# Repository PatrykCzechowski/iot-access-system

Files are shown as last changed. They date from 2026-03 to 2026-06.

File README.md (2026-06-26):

# AccessControl

An IoT access control system: contactless NFC cards are read by ESP32-based
readers, access rights are verified centrally by a .NET backend, and electric
locks are released over MQTT. The whole system is managed from a Blazor
WebAssembly admin panel.

**Stack:** .NET 10 (Clean Architecture + CQRS) · Blazor WebAssembly + MudBlazor 9 ·
PostgreSQL (EF Core) · MQTT (Mosquitto) · SignalR · mDNS · ESP32-S3 firmware
(PlatformIO) · Docker Compose.

## Features

- Contactless NFC card authorization with server-side permission checks.
- Access model: **Card → Cardholder → Access Profile → Zones**.
- Device management: mDNS auto-discovery, remote MQTT provisioning, per-device
  configuration, live online/offline status.
- Card enrollment straight from a reader (enrollment mode).
- Full audit trail of every access attempt (granted **and** denied), streamed
  live to the UI via SignalR.
- JWT authentication with the `Admin` role, forced password change on first
  login, and rate-limited auth endpoints.

## Web UI

The administration panel is a Blazor WebAssembly app (MudBlazor, Material
Design 3). Screenshots below are captured from a running instance with seeded
demo data and live access logs.

<table>
<tr>
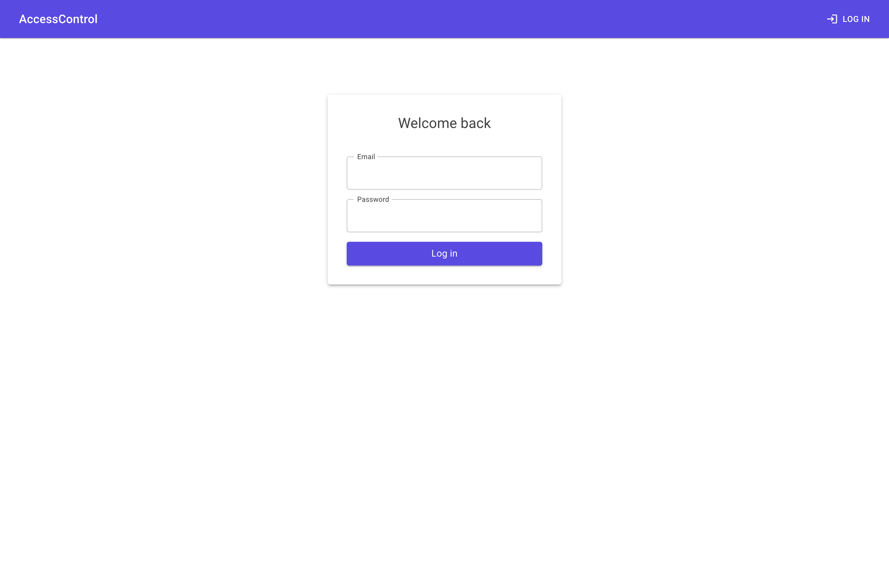
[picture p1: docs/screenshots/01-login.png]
Login screen
<td width="50%"><br><sub><b>Login</b> — JWT authentication</sub></td>
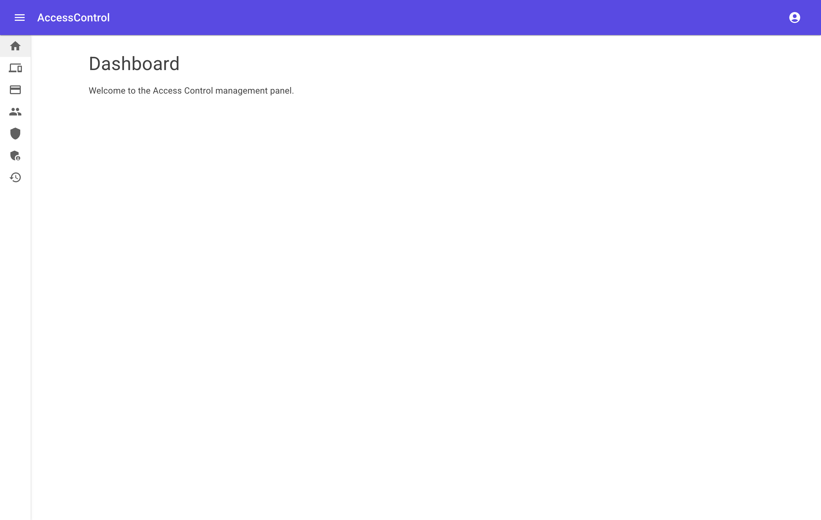
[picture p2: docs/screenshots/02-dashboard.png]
Dashboard
<td width="50%"><br><sub><b>Dashboard</b> — management home</sub></td>
</tr>
<tr>
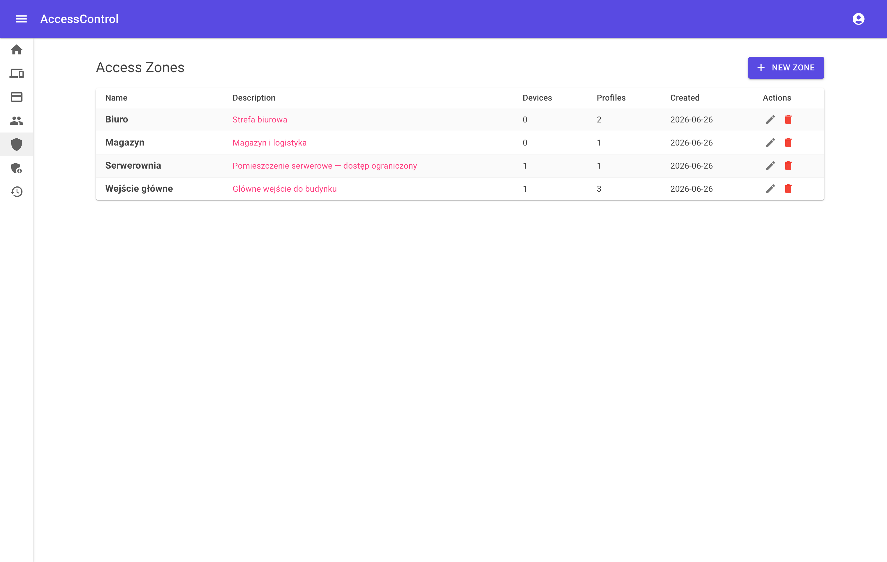
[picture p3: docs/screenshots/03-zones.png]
Zones
<td width="50%"><br><sub><b>Zones</b> — physical access areas</sub></td>
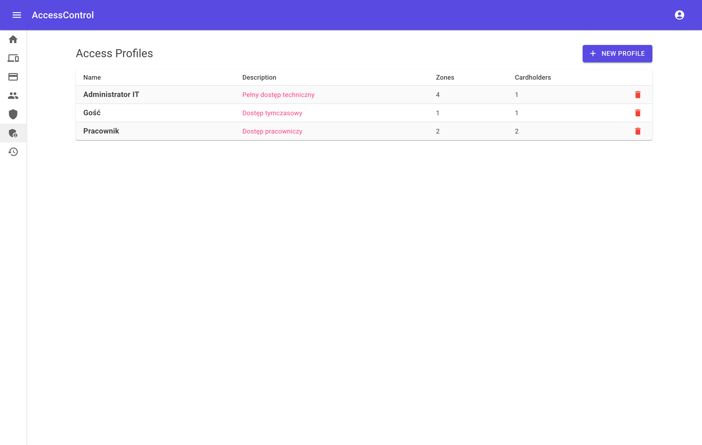
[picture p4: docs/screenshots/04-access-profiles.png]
Access profiles
<td width="50%"><br><sub><b>Access Profiles</b> — permission sets over zones</sub></td>
</tr>
<tr>
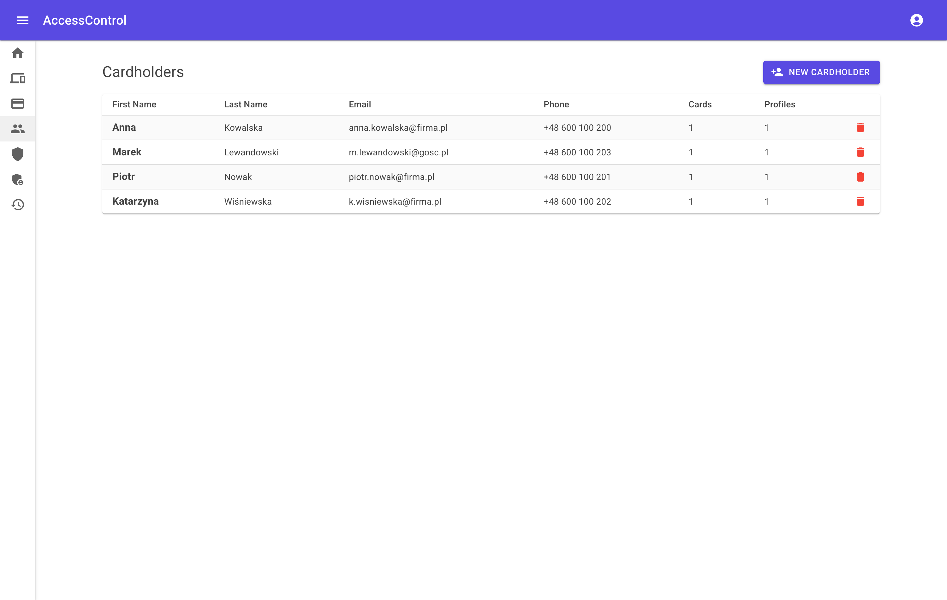
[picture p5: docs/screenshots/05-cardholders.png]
Cardholders
<td width="50%"><br><sub><b>Cardholders</b> — people and their profiles</sub></td>
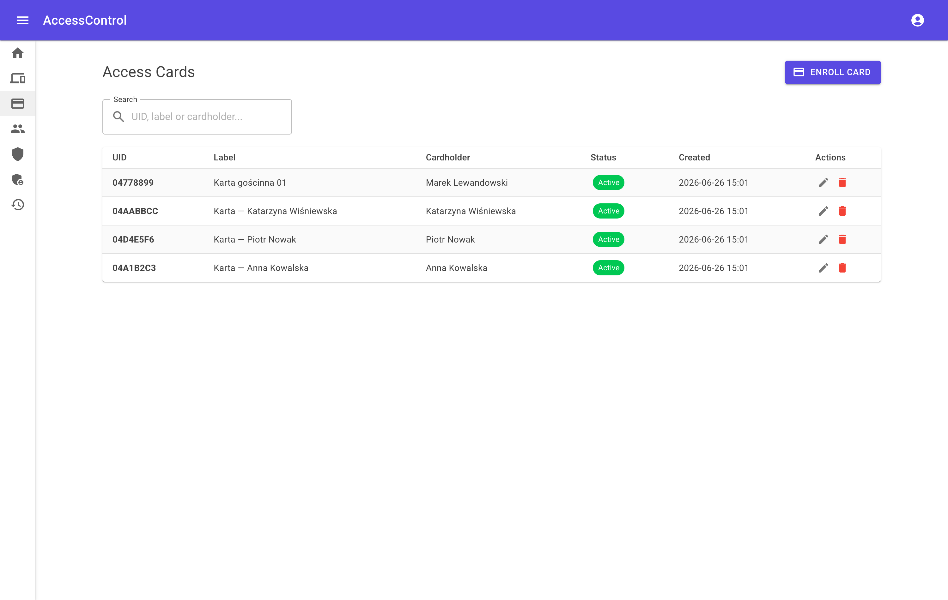
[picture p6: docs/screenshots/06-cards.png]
Cards
<td width="50%"><br><sub><b>Cards</b> — NFC cards, status and assignment</sub></td>
</tr>
<tr>
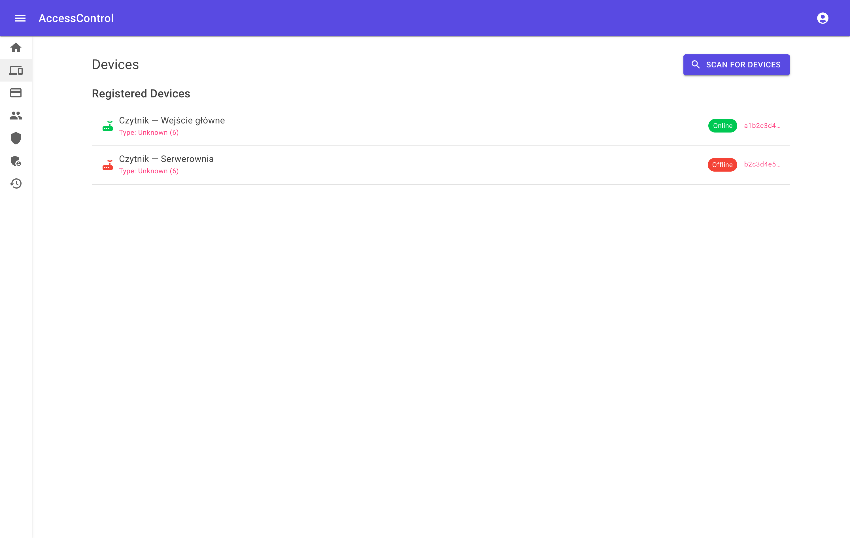
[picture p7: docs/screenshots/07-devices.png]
Devices
<td width="50%"><br><sub><b>Devices</b> — readers/locks with online status</sub></td>
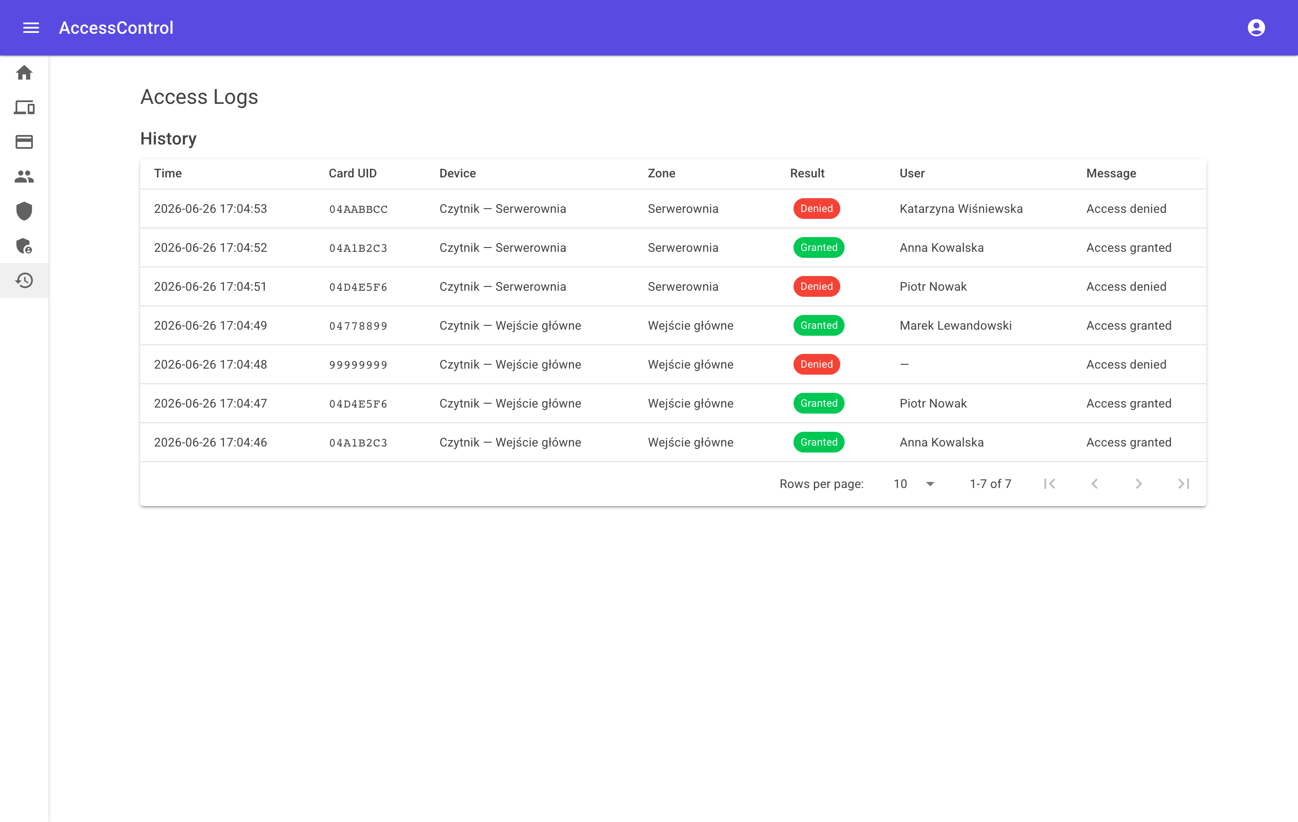
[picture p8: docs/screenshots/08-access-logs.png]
Access logs
<td width="50%"><br><sub><b>Access Logs</b> — live audit (granted / denied)</sub></td>
</tr>
</table>

> Screenshots live in [`docs/screenshots/`](docs/screenshots/) and are captured
> with Playwright driving Google Chrome against the running UI.

## Documentation

The PDFs are **build artifacts** generated from source — they are git-ignored
and produced on demand by the scripts below (output written to `docs/`).

| Generated file | Contents | Source |
|---|---|---|
| `docs/dokumentacja-projektu.pdf` | Full project documentation — technical, service and user guide (PL) | [`generate_project_docs.py`](docs/tools/generate_project_docs.py) |
| `docs/prezentacja-projektu.pdf` | Project presentation deck, includes the UI screenshots (PL) | [`generate_project_docs.py`](docs/tools/generate_project_docs.py) |
| `docs/elektronika.pdf` · `electronics.pdf` | Electronics specification — BOM, pinout, protocols, EEPROM map (PL · EN) | [`docs/elektronika.md`](docs/elektronika.md) · [`generate_pdf.py`](docs/tools/generate_pdf.py) |

Generate them with Python ([fpdf2](https://py-pdf.github.io/fpdf2/)):

```bash
pip install -r docs/tools/requirements.txt
python docs/tools/generate_pdf.py            # electronics spec (PL + EN)
python docs/tools/generate_project_docs.py   # project docs + presentation (PL)
```

## Requirements

- [.NET 10 SDK](https://dotnet.microsoft.com/download)
- [Docker & Docker Compose](https://docs.docker.com/get-docker/)

---

## Run with Docker Compose

```bash
cp .env.example .env
```

Edit `.env` and set your own values, then:

```bash
docker compose up --build
```

- **API:** http://localhost:8080
- **Health:** http://localhost:8080/health

---

## Run locally

> **Working with ESP32 firmware?** Use this mode — mDNS advertisements must
> reach your physical LAN so ESP32 devices can discover the API and MQTT broker.
> Running the API inside Docker isolates mDNS to the container network.

### 1. Start infrastructure (Mosquitto + PostgreSQL)

```bash
cp .env.example .env        # first time only — edit passwords if needed
docker compose -f docker-compose.infra.yml up -d
```

### 2. Configure secrets

```bash
cd src/AccessControl.Api

dotnet user-secrets set "Jwt:Key" "<random-string-min-32-chars>"
dotnet user-secrets set "ConnectionStrings:DefaultConnection" "Host=localhost;Port=5432;Database=access_db;Username=db_user;Password=access_pass"
dotnet user-secrets set "Admin:Email" "admin@example.com"
dotnet user-secrets set "Admin:Password" "Admin1234!"
```

### 3. Start API and UI

```bash
dotnet run --project src/AccessControl.Api
dotnet run --project src/AccessControl.UI        # separate terminal
```

- **API:** https://localhost:7157 (HTTP: http://localhost:5104)
- **UI:** https://localhost:7003
- **Scalar UI:** https://localhost:7157/scalar/v1
- **Health:** https://localhost:7157/health

Migrations and admin account seeding are applied automatically on startup.

#### Default credentials (local dev)

| Service | Key | Value |
|---|-----|---|
| Admin account | Email | `admin@accesscontrol.local` |
| Admin account | Password | `Admin123!` |
| PostgreSQL | User | `access_user` |
| PostgreSQL | Password | `access_pass` |
| PostgreSQL | Database | `access_db` |

The admin account is created with `MustChangePassword = true` — you will be prompted to change the password on first login.

> **Network binding:** The API listens on `0.0.0.0:5104` (all interfaces) so
> ESP32 devices on the local network can reach it. Do **not** run this on an
> untrusted or public network without a firewall.
>
> **Provisioning security:** MQTT credentials are pushed to devices over
> plain HTTP because ESP32 does not support TLS. This is acceptable on a
> trusted LAN but means credentials can be observed by anyone on the same
> network segment. Use per-device or scoped MQTT credentials in production.

### 4. Flash firmware

The card reader firmware runs on an **Arduino Nano ESP32** (ESP32-S3) and is
managed with [PlatformIO](https://platformio.org/).

#### Prerequisites

- [PlatformIO Core (CLI)](https://docs.platformio.org/en/latest/core/installation/index.html)
  (`pip install platformio`) or the
  [PlatformIO IDE extension](https://marketplace.visualstudio.com/items?itemName=platformio.platformio-ide) for VS Code.
- USB cable connected to the Nano ESP32.

#### Build

```bash
cd firmware/card-reader-standalone
pio run
```

#### Upload (flash)

```bash
cd firmware/card-reader-standalone
pio run -t upload
```

PlatformIO will auto-detect the port. If it fails, specify it explicitly:

```bash
pio run -t upload --upload-port COM9        # Windows
pio run -t upload --upload-port /dev/ttyUSB0  # Linux / macOS
```

> **Nano ESP32 DFU note:** The board uses DFU upload (not classic serial).
> If the flash completes but the device doesn't restart, press the **RESET**
> button (or double-tap it) to boot the new firmware.

#### Monitor serial output

```bash
pio device monitor --baud 115200
```

#### After flashing

The ESP32 will:
1. Connect to WiFi (captive portal on first boot — connect to `AccessControl-XXYY` AP).
2. Advertise itself via mDNS (`_accesscontrol._tcp`) with device info (hwid, model, features).
3. Start an HTTP server on port 80 and wait for MQTT config push from the backend.
4. In the UI: **Scan for Devices** → **Add** the device → backend automatically pushes MQTT credentials.
5. Device receives config, restarts, connects to MQTT, and starts scanning cards.

**Troubleshooting:**

- **Re-provision MQTT** — open device detail page in UI, click "Push MQTT Config".
  Alternatively: send `mqtt_reset` via Serial Monitor → reboot → device returns to provisioning mode.
- **Set broker manually** — send `mqtt_set <ip> [port]` via Serial Monitor.
- **Device not found in scan** — ensure the API is running on the same LAN
  as the ESP32 (not inside Docker). mDNS requires multicast networking.
- **NFC not detected** (`nfc:false` in heartbeat) — power-cycle the board;
  DFU flashing can leave the I2C bus stuck (the firmware recovers on boot).

---

## Hardware wiring — Card Reader + Lock Controller (all-in-one)

**Board:** Arduino Nano ESP32 (ESP32-S3)

### Components

| Component | Notes |
|---|---|
| PN532 NFC module | I2C mode: DIP SW1=ON, SW2=OFF |
| RGB LED (common cathode) | 3× resistors required |
| Buzzer TMB12A05 | Active buzzer 5 V — requires NPN transistor driver |
| HW-482 relay module | Controls the electric lock |
| Electric lock | Connected to relay NO/COM terminals |
| Reset button (momentary) | Hold during boot for factory reset |

### Pin assignments

| Signal | Arduino pin | GPIO | Notes |
|---|---|---|---|
| PN532 SDA | A4 | GPIO11 | 4.7 kΩ pull-up to 3V3 |
| PN532 SCL | A5 | GPIO12 | 4.7 kΩ pull-up to 3V3 |
| PN532 VCC | 3V3 | — | |
| PN532 GND | GND | — | |
| LED Red anode | D2 | GPIO5 | 150 Ω in series |
| LED Green anode | D3 | GPIO6 | 100 Ω in series |
| LED Blue anode | D4 | GPIO7 | 33 Ω in series |
| LED cathode (common) | GND | — | |
| Buzzer | D5 | GPIO8 | 1 kΩ to NPN base (S8050/BC547/2N2222) |
| HW-482 IN1 | D6 | GPIO9 | Active LOW |
| HW-482 VCC | VUSB | — | 5 V |
| HW-482 GND | GND | — | |
| Factory reset button | D7 | GPIO10 | INPUT_PULLUP — other leg to GND |

### Resistor values

| Resistor | Value | Purpose |
|---|---|---|
| R1 | 150 Ω | LED Red (Vf ≈ 2.0 V, I ≈ 10 mA) |
| R2 | 100 Ω | LED Green (Vf ≈ 2.1 V, I ≈ 10 mA) |
| R3 | 33 Ω | LED Blue (Vf ≈ 3.2 V, I ≈ 3 mA) |
| R4 | 4.7 kΩ | I2C SDA pull-up |
| R5 | 4.7 kΩ | I2C SCL pull-up |
| R6 | 1 kΩ | NPN transistor base (buzzer driver) |

### Buzzer driver circuit (NPN)

The TMB12A05 runs at 5 V / ~30–100 mA — beyond GPIO drive capability.
Use an NPN transistor (S8050, BC547 or 2N2222):

```
GPIO8 (D5) ── 1 kΩ ── Base
                       NPN transistor
              Emitter ── GND
              Collector ── Buzzer (−)
              Buzzer (+) ── VUSB (5 V)

Add 1N4148 diode: anode → Collector, cathode → 5 V  (flyback protection)
```

### HW-482 relay — lock wiring

```
HW-482 COM ──── (+) power supply of the lock (e.g. 12 V)
HW-482 NO  ──── (+) terminal of the electric lock
Lock (−)   ──── (−) power supply of the lock
```

Use **NO** (Normally Open) = fail-secure: lock is closed when power is off.
Use **NC** (Normally Closed) = fail-safe: lock opens when power is off (fire-safety requirement).

### Factory reset procedure

1. Press and hold the reset button (D7 ↔ GND).
2. While holding — apply power (or press the board RESET button).
3. Hold for **3 seconds** — LED blinks red during countdown.
4. On success: **3× beep + white LED flash** → device restarts.
5. Device boots into WiFi provisioning AP: `AccessControl-XXYY`.

Releasing the button before 3 s cancels the reset (normal boot).

**What is cleared:**

| Data | Cleared? |
|---|---|
| WiFi credentials | Yes |
| MQTT broker config | Yes |
| Device configuration (timers, buzzer, LED) | Yes |
| Hardware ID (HWID) | **No** — device keeps its identity in the system |

---

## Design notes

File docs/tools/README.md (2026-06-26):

# docs/tools

Helper scripts for generating project documentation PDFs.

## Prerequisites

```bash
pip install -r docs/tools/requirements.txt
```

## Usage

### Electronics specification

```bash
python docs/tools/generate_pdf.py
```

Generates two files in `docs/`:

| File | Language |
|---|---|
| `elektronika.pdf` | Polish |
| `electronics.pdf` | English |

Both PDFs contain the full electronics specification: BOM, pinout with resistor values, component descriptions, communication protocols, EEPROM map, power requirements, and firmware dependencies.

### Project documentation + presentation

```bash
python docs/tools/generate_project_docs.py
```

Generates two files in `docs/`:

| File | Content |
|---|---|
| `dokumentacja-projektu.pdf` | Documentation: technical + service + user (Polish) |
| `prezentacja-projektu.pdf` | Project presentation, slide deck (Polish, landscape) |

The documentation covers software architecture, the data model, the access-control flow,
hardware/protocols, REST API, diagnostics, provisioning, factory reset, troubleshooting,
firmware updates, and an end-user guide for the web panel and the reader.

Fonts are resolved automatically for macOS / Windows / Linux (Polish glyphs required).

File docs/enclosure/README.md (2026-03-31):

# Obudowa IoT Access Control — ESP8266 + PN532 NFC

Parametryczny model obudowy w OpenSCAD dla modułów Wemos D1 Mini (ESP8266) i PN532 NFC/RFID V3.

## Wymagania

- [OpenSCAD](https://openscad.org/downloads.html) (>= 2021.01)
- Po instalacji dodaj do PATH: `C:\Program Files\OpenSCAD`

## Struktura plików

```
docs/enclosure/
├── enclosure.scad          # Główny model parametryczny
├── build.ps1               # Skrypt budowania STL
└── README.md               # Ten plik
```

## Szybki start

### 1. Podgląd GUI
```powershell
openscad .\enclosure.scad
```

### 2. Eksport STL z terminala
```powershell
# Dolna część obudowy
openscad -o enclosure_bottom.stl -D "part=""bottom""" enclosure.scad

# Górna pokrywa (odwrócona do druku)
openscad -o enclosure_top.stl -D "part=""top""" enclosure.scad

# Złożony widok (do podglądu)
openscad -o enclosure_assembled.stl -D "part=""assembled""" enclosure.scad
```

### 3. Automatyczny build
```powershell
.\build.ps1           # Buduje bottom + top STL
.\build.ps1 -Preview  # Otwiera podgląd w OpenSCAD
```

## Parametry do dostrojenia

| Parametr | Domyślnie | Opis |
|---|---|---|
| `tol` | 0.3 mm | Tolerancja druku 3D |
| `wall` | 2.0 mm | Grubość ścianki |
| `nfc_wall` | 1.5 mm | Grubość nad anteną NFC (max 2mm!) |
| `corner_r` | 3.0 mm | Promień zaokrąglenia |

Zmiana parametru z terminala:
```powershell
openscad -o custom.stl -D "wall=2.5" -D "nfc_wall=1.2" -D "part=""bottom""" enclosure.scad
```

## Wskazówki druku 3D

- **Materiał:** PLA/PETG (NFC przechodzi przez oba)
- **Warstwa:** 0.2 mm (standardowa jakość)
- **Wypełnienie:** 20-30%
- **Podpory:** Nie wymagane (obie części drukowane płaską stroną)
- **Orientacja:** Dolna część — dnem do dołu, górna — już odwrócona w STL

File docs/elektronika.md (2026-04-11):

# Specyfikacja Projektu — Elektronika

## AccessControl Card Reader + Lock Controller v2.0

**Model:** NanoESP32-CardReader  
**Firmware:** 2.0.0  
**Data:** 2026-04-11

---

## 1. BOM — Spis elementów elektronicznych

| # | Element | Oznaczenie | Ilość | Opis |
|---|---|---|---|---|
| 1 | Arduino Nano ESP32 | U1 | 1 | Mikrokontroler ESP32-S3, moduł deweloperski, USB-C |
| 2 | PN532 NFC/RFID Module | U2 | 1 | Moduł czytnika NFC/RFID 13.56 MHz, interfejs I2C |
| 3 | HW-482 Relay Module | K1 | 1 | Moduł przekaźnika 1-kanałowy, sterowanie active LOW, 5V |
| 4 | RGB LED (Common Cathode) | LED1 | 1 | Dioda LED RGB ze wspólną katodą, 5mm |
| 5 | TMB12A05 Active Buzzer | BZ1 | 1 | Buzzer aktywny 5V, ⌀12mm |
| 6 | Przycisk chwilowy (tact switch) | SW1 | 1 | Przycisk Reset/Factory Reset, NO |
| 7 | Przewody połączeniowe | — | ~15 | Dupont male-female / male-male |
| 8 | Zasilacz USB 5V | — | 1 | Zasilanie przez USB-C mikrokontrolera |

---

## 2. Schemat elektryczny — Pinout

### 2.1 Tabela połączeń

| Komponent | Pin komponentu | Pin ESP32 (Arduino) | Pin ESP32 (GPIO) | Uwagi |
|---|---|---|---|---|
| **PN532** | SDA | A4 | GPIO11 | Domyślna linia I2C SDA |
| **PN532** | SCL | A5 | GPIO12 | Domyślna linia I2C SCL |
| **PN532** | VCC | 3V3 | — | Zasilanie 3.3V |
| **PN532** | GND | GND | — | Masa |
| **RGB LED** | R (Red) | D2 | GPIO5 | Czerwony — wyjście cyfrowe |
| **RGB LED** | G (Green) | D3 | GPIO6 | Zielony — wyjście cyfrowe |
| **RGB LED** | B (Blue) | D4 | GPIO7 | Niebieski — wyjście cyfrowe |
| **RGB LED** | Katoda (–) | GND | — | Wspólna katoda → masa |
| **Buzzer** | + (sygnał) | D5 | GPIO8 | Sterowanie HIGH/LOW |
| **Buzzer** | – | GND | — | Masa |
| **HW-482 Relay** | IN1 | D6 | GPIO9 | **Active LOW** — LOW = otwarty |
| **HW-482 Relay** | VCC | 5V (VUSB) | — | Zasilanie 5V z USB |
| **HW-482 Relay** | GND | GND | — | Masa |
| **Reset Button** | Pin 1 | D7 | GPIO10 | INPUT_PULLUP, przytrzymać 3s przy starcie |
| **Reset Button** | Pin 2 | GND | — | Masa |

### 2.2 Konfiguracja DIP Switch modułu PN532

| Switch | Pozycja | Tryb |
|---|---|---|
| SW1 | **ON** | I2C |
| SW2 | **OFF** | I2C |

> Adres I2C modułu PN532: **0x24** (domyślny)

---

## 3. Opis użytych elementów

### 3.1 Arduino Nano ESP32 (ESP32-S3)

| Parametr | Wartość |
|---|---|
| Chipset | Espressif ESP32-S3 |
| Rdzeń | Dual-core Xtensa LX7, do 240 MHz |
| RAM | 512 KB SRAM + 8 MB PSRAM |
| Flash | 16 MB |
| WiFi | 802.11 b/g/n, 2.4 GHz |
| Bluetooth | BLE 5.0 (nieużywany w projekcie) |
| USB | USB-C (natywne USB OTG) |
| Napięcie logiki | 3.3V |
| Wyjścia zasilania | 3V3 (3.3V), 5V (VUSB — bezpośrednio z USB) |
| Wymiary | 45 × 18 mm |
| Interfejsy | I2C, SPI, UART, GPIO, ADC, DAC |
| Obudowa | Moduł DIP, zgodny z pinoutem Arduino Nano |
| Pamięć nieulotna | EEPROM (emulowana we Flash), Preferences API (NVS) |

**Uwagi:**
- Domyślne piny I2C (`Wire.begin()`) na Nano ESP32 to GPIO21/GPIO22, **nie** A4/A5. Firmware ręcznie inicjalizuje `Wire.begin(A4, A5)`.
- Timeout I2C ustawiony na 3000 ms (clock stretching dla operacji RF na PN532).
- Upload firmware przez protokół DFU (USB).

### 3.2 PN532 NFC/RFID Module

| Parametr | Wartość |
|---|---|
| Chipset | NXP PN532 |
| Standardy NFC | ISO/IEC 14443A/B, FeliCa, ISO/IEC 18092 |
| Częstotliwość | 13.56 MHz |
| Odczyt kart | MIFARE Classic 1K/4K, MIFARE Ultralight, NTAG21x |
| Interfejsy | I2C, SPI, UART (wybór switch DIP) |
| Napięcie zasilania | 3.3V – 5.5V |
| Prąd pracy | ~100 mA (podczas skanowania RF) |
| Zasięg odczytu | ~5 cm (zależy od anteny i karty) |
| Moduł | Breakout board z wbudowaną anteną PCB |
| Adres I2C | 0x24 |
| Biblioteka | Adafruit PN532 v1.3.4 |

**Uwagi:**
- Tryb pracy: polling I2C (bez pinu IRQ — parametr `-1` w konstruktorze).
- `setPassiveActivationRetries(1)` — 1 retry = 2 próby RF na odczyt.
- Przed `Wire.begin()` firmware wykonuje **I2C bus recovery** (18 impulsów zegara + STOP) — zapobiega zawieszeniu magistrali po restarcie ESP32 w trakcie transmisji.

### 3.3 HW-482 Relay Module (1-kanałowy)

| Parametr | Wartość |
|---|---|
| Kanały | 1 |
| Napięcie sterowania | 5V |
| Wejście sterujące | Active LOW (LOW = przekaźnik załączony) |
| Obciążalność styku | AC 250V/10A, DC 30V/10A |
| Izolacja | Optoizolacja (optocoupler) |
| Zasilanie | 5V DC (z pinu VUSB na ESP32) |
| Wskaźnik | LED na płytce modułu |
| Wymiary | ~50 × 26 × 18 mm |

**Logika sterowania:**
- `digitalWrite(RELAY_PIN, LOW)` → przekaźnik **otwarty** (zamek odblokowany)
- `digitalWrite(RELAY_PIN, HIGH)` → przekaźnik **zamknięty** (zamek zablokowany) — stan domyślny

### 3.4 RGB LED (Common Cathode)

| Parametr | Wartość |
|---|---|
| Typ | LED RGB 5mm, wspólna katoda |
| Kolory | Czerwony, Zielony, Niebieski |
| Napięcie przewodzenia | R: ~2.0V, G: ~3.0V, B: ~3.0V |
| Prąd roboczy | 20 mA na kolor |
| Sterowanie | Cyfrowe (HIGH/LOW), bez PWM |

**Sygnalizacja kolorami:**
| Kolor | Znaczenie |
|---|---|
| Niebieski | Gotowy — normalny tryb, NFC dostępne |
| Pomarańczowy (R+G) | NFC niedostępne |
| Zielony | Dostęp przyznany |
| Czerwony | Dostęp odmówiony |
| Żółty (R+G) | Oczekiwanie na provisioning MQTT |
| Fioletowy (R+B) | Tryb enrollment (mruganie) |
| Biały (R+G+B) | Factory reset potwierdzony |

### 3.5 TMB12A05 Active Buzzer

| Parametr | Wartość |
|---|---|
| Typ | Buzzer aktywny (wbudowany generator) |
| Napięcie pracy | 5V DC |
| Częstotliwość dźwięku | ~2300 Hz (stała) |
| Prąd | ~30 mA |
| Średnica | 12 mm |
| Sterowanie | Proste HIGH/LOW |

**Wzorce dźwiękowe:**
| Wzorzec | Znaczenie |
|---|---|
| 1× krótki beep (80 ms) | OK / potwierdzenie |
| 2× beep (80+80 ms) | Dostęp przyznany / zamek otwarty |
| 3× szybki beep (60 ms) | Błąd / dostęp odmówiony |

### 3.6 Przycisk chwilowy (Tact Switch)

| Parametr | Wartość |
|---|---|
| Typ | Momentary push button (NO) |
| Podciąganie | Wewnętrzne INPUT_PULLUP (ESP32) |
| Logika | Active LOW (wciśnięty = LOW) |
| Funkcja | Factory reset (3s hold przy starcie) |

---

## 4. Magistrale i protokoły komunikacyjne

### 4.1 I2C (Inter-Integrated Circuit)

| Parametr | Wartość |
|---|---|
| Zastosowanie | Komunikacja ESP32 ↔ PN532 |
| Linie | SDA (A4/GPIO11), SCL (A5/GPIO12) |
| Napięcie logiki | 3.3V |
| Tryb | Master (ESP32) — Slave (PN532) |
| Adres slave | 0x24 (PN532) |
| Timeout | 3000 ms (clock stretching) |
| Prędkość | Standard Mode (100 kHz) |
| Pull-upy | Na module PN532 (wbudowane) |

**Odzyskiwanie magistrali (Bus Recovery):**
Firmware implementuje procedurę odzyskiwania I2C przy starcie — 18 impulsów zegara + sygnał STOP — aby zwolnić linię SDA, jeśli PN532 trzyma ją nisko po niespodziewanym resecie.

### 4.2 WiFi (IEEE 802.11)

| Parametr | Wartość |
|---|---|
| Standard | 802.11 b/g/n |
| Pasmo | 2.4 GHz |
| Tryb | Station (STA) |
| Provisioning | Captive Portal (WiFiManager) |
| Timeout AP | 180 sekund |
| Nazwa AP | `AccessControl-XXYY` (XX/YY = ostatnie 2 bajty MAC) |
| Hostname | `ac-XXXXXXXX` (8 znaków HWID) |

**Przepływ provisioning WiFi:**
1. Przy pierwszym uruchomieniu (lub po factory reset) ESP32 tworzy Access Point.
2. Użytkownik łączy się z AP i konfiguruje WiFi przez captive portal.
3. Dane WiFi zapisywane w NVS (Flash) — przetrwają restart.

### 4.3 MQTT (Message Queuing Telemetry Transport)

| Parametr | Wartość |
|---|---|
| Zastosowanie | Komunikacja urządzenie ↔ serwer backend |
| Broker | Mosquitto (docker) lub dowolny MQTT 3.1.1 |
| Port | Konfigurowalny (domyślny: 1883) |
| QoS subskrypcji | 1 (at least once) |
| Keep-alive | 60 sekund |
| LWT (Last Will) | `accesscontrol/{hwid}/heartbeat` → `{"status":"offline"}` (retain) |
| Bufor wiadomości | 512 bajtów |
| Biblioteka | PubSubClient v2.8 |
| Reconnect | Exponential backoff: 2s → 4s → 8s → ... → 30s (max) |

**Przestrzeń nazw topiców:**

```
accesscontrol/{hwid}/
├── announce          (PUB, retain) — ogłoszenie urządzenia
├── heartbeat         (PUB, retain) — status online/offline + uptime, RSSI, heap
├── card/
│   ├── scanned       (PUB) — karta odczytana w trybie normalnym
│   ├── enrolled      (PUB) — karta odczytana w trybie enrollment
│   ├── enroll        (SUB) — rozpoczęcie/anulowanie enrollment
│   └── result        (SUB) — wynik weryfikacji karty (granted/denied)
├── config/
│   ├── set           (SUB) — nowa konfiguracja urządzenia
│   └── ack           (PUB) — potwierdzenie zastosowania konfiguracji
└── lock/
    ├── command        (SUB) — komenda open/close zamka
    └── status         (PUB) — status zamka (open/closed)
```

**Provisioning MQTT:**
- Przez HTTP POST na `http://<ip>/api/provision` z JSON `{"broker":"...", "port":..., "username":"...", "password":"..."}`
- Przez komendę serialową: `mqtt_set <ip> [port]`
- Zapis w EEPROM (adres 96–227)

### 4.4 mDNS (Multicast DNS)

| Parametr | Wartość |
|---|---|
| Zastosowanie | Automatyczne odkrywanie urządzeń w sieci lokalnej |
| Typ usługi | `_accesscontrol._tcp` |
| Port | 80 |
| Hostname | `ac-XXXXXXXX.local` |

**Rekordy TXT:**

| Klucz | Wartość | Opis |
|---|---|---|
| `hwid` | UUID urządzenia | Unikalny identyfikator (UUID v5-like z MAC) |
| `model` | `NanoESP32-CardReader` | Model urządzenia |
| `mac` | `XX:XX:XX:XX:XX:XX` | Adres MAC |
| `features` | `17` | Maska bitowa funkcji (card reader + lock) |
| `fw` | `2.0.0` | Wersja firmware |

### 4.5 HTTP (Provisioning Server)

| Parametr | Wartość |
|---|---|
| Port | 80 |
| Endpoint | `POST /api/provision` |
| Content-Type | `application/json` |
| Aktywny | Tylko gdy MQTT nie jest skonfigurowany |
| Biblioteka | WebServer (ESP32 wbudowany) |

### 4.6 UART (Serial)

| Parametr | Wartość |
|---|---|
| Zastosowanie | Debug / komendy serwisowe |
| Prędkość | 115200 baud |
| Komendy | `help`, `mqtt_set <ip> [port]`, `mqtt_reset` |

---

## 5. Mapa pamięci EEPROM

| Adres | Rozmiar | Magic Byte | Dane |
|---|---|---|---|
| 0 | 1 B | `0xAC` | Device ID magic |
| 1–36 | 36 B | — | HWID (UUID, string ASCII) |
| 64 | 1 B | `0xD0` | Config magic |
| 65–78 | 14 B | — | Konfiguracja urządzenia (heartbeat, enrollment timeout, buzzer, LED, lock duration) |
| 96 | 1 B | `0x4D` | MQTT config magic |
| 97–160 | 64 B | — | Broker address (string) |
| 161–162 | 2 B | — | Port (uint16, little-endian) |
| 163–194 | 32 B | — | Username (string) |
| 195–226 | 32 B | — | Password (string) |

**Łączny rozmiar EEPROM:** 256 bajtów

---

## 6. Wymagania zasilania

| Źródło | Napięcie | Odbiorcy |
|---|---|---|
| USB-C | 5V | ESP32, Buzzer (TMB12A05), Relay (HW-482) |
| Regulator ESP32 | 3.3V | PN532, RGB LED, logika ESP32 |

**Szacunkowy pobór prądu:**
| Stan | Prąd (szacunkowo) |
|---|---|
| Idle (WiFi + MQTT) | ~80 mA |
| Skanowanie NFC | ~180 mA |
| Przekaźnik aktywny | +70 mA |
| Buzzer aktywny | +30 mA |
| **Max (wszystko naraz)** | **~360 mA** |

---

## 7. Zależności — Biblioteki firmware

| Biblioteka | Wersja | Zastosowanie |
|---|---|---|
| Adafruit PN532 | ^1.3.4 | Komunikacja z czytnikiem NFC (I2C) |
| PubSubClient | ^2.8 | Klient MQTT |
| WiFiManager | ^2.0.17 | Konfiguracja WiFi przez Captive Portal |
| ArduinoJson | ^7.4.1 | Parsowanie / budowanie JSON |
| Wire (wbudowana) | — | Magistrala I2C |
| WiFi (wbudowana) | — | Obsługa WiFi ESP32 |
| ESPmDNS (wbudowana) | — | Rozgłaszanie usługi mDNS |
| WebServer (wbudowana) | — | Serwer HTTP do provisioningu |
| EEPROM (wbudowana) | — | Zapis konfiguracji w pamięci Flash |

**Platforma:** PlatformIO, `espressif32`, board `arduino_nano_esp32`, framework Arduino.

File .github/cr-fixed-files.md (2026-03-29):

# Pliki poprawione w ramach CR Fix (2026-03-29)

Poniższe pliki zostały zmodyfikowane w ramach wdrażania poprawek z Code Review.
Przy kolejnej iteracji CR można je wykluczyć z zakresu przeglądu.

## Iteracja 1

- `src/AccessControl.Application/Cards/Commands/CreateAccessCardCommandHandler.cs`
- `src/AccessControl.Domain/Entities/Device.cs`
- `src/AccessControl.Domain/Entities/AccessCard.cs`
- `src/AccessControl.Api/Infrastructure/GlobalExceptionHandler.cs`
- `src/AccessControl.Infrastructure/Mqtt/MqttClientService.cs`
- `src/AccessControl.Infrastructure/Mqtt/MqttBrokerMdnsAdvertiser.cs`

## Iteracja 2

- `src/AccessControl.Infrastructure/Mqtt/CardEnrollmentService.cs`
- `src/AccessControl.Application/Devices/Commands/CancelEnrollmentCommandHandler.cs`
- `src/AccessControl.Infrastructure/Mqtt/Handlers/CardReadMqttHandler.cs`
- `src/AccessControl.Infrastructure/Mqtt/Handlers/CardEnrolledMqttHandler.cs`
- `src/AccessControl.Infrastructure/Devices/Discovery/DeviceDiscoveryService.cs`
- `src/AccessControl.Api/Endpoints/CardEndpoints.cs`
- `src/AccessControl.Api/Endpoints/DeviceEndpoints.cs`
- `src/AccessControl.Infrastructure/Mqtt/Handlers/AnnounceMqttHandler.cs`

## Iteracja 3

- `src/AccessControl.Infrastructure/Mqtt/CardAccessService.cs`
- `src/AccessControl.Application/Devices/Commands/UpdateDeviceConfigCommandHandler.cs`
- `src/AccessControl.Infrastructure/Mqtt/Handlers/ConfigAckMqttHandler.cs`
- `src/AccessControl.Infrastructure/Mqtt/Handlers/LockStatusMqttHandler.cs`
- `src/AccessControl.Application/Common/Interfaces/IDeviceRepository.cs`
- `src/AccessControl.Infrastructure/Devices/DeviceRepository.cs`

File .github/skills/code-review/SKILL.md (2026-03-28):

---
name: code-review
description: "Rigorous Code Review of Git changes. Use when: code review, CR, review changes, przegląd kodu, sprawdź zmiany, review PR, git diff review. Automatically fetches Git diff and evaluates code against Clean Code, Clean Architecture, SOLID, DRY, KISS, YAGNI, testability, performance, and security."
argument-hint: "Optional: base branch or commit range (e.g. 'main', 'HEAD~3'). Default: staged + unstaged changes."
---

# Code Review — Senior Engineer & Software Architect

You are an experienced Senior Software Engineer and Software Architect. You conduct rigorous but constructive Code Reviews.

## Procedure

### 1. Fetch changes from Git

Determine the diff scope based on user argument:

| User argument | Command |
|---|---|
| None | `git diff HEAD` (unstaged + staged vs last commit) |
| Branch name (e.g. `main`) | `git diff main...HEAD` (changes relative to base branch) |
| Commit range (e.g. `HEAD~3`) | `git diff HEAD~3` |
| `--staged` | `git diff --staged` |

Run the appropriate command in the terminal. If the diff is empty, try `git diff --staged`. If still empty — inform the user that there are no changes to review.

If the diff is very large (>500 lines), process file by file using `git diff [range] -- <path>`.

### 2. Identify changed files

Run `git diff --name-only [range]` to get the list of changed files. For each file with significant changes, read the full context (entire file or key sections) to understand the architecture and dependencies.

### 3. Perform analysis

Evaluate code against the criteria below, assigning a priority to each finding:

#### 🔴 Critical (merge blockers)
- Logic errors, race conditions, deadlocks
- Violation of layer separation (business logic in controllers/UI/infrastructure)
- Dependency Inversion violation — domain depending on framework, database, or UI
- Security vulnerabilities (SQL injection, XSS, missing authorization, secrets in code)
- Memory leaks, unclosed resources

#### 🟡 Significant (should be fixed)
- SOLID violations (especially SRP, OCP, DIP)
- DRY violations — duplicated logic
- Cyclomatic complexity >10
- N+1 query problems
- Missing validation at system boundaries (API inputs, files, external data)
- Mixed responsibilities in classes/methods
- Tight coupling hindering testability

#### 🟢 Suggestions (nice-to-have)
- Variable/method naming not following conventions
- Methods longer than ~20 lines that could be split
- Missing abstractions (interfaces) for easier testing
- KISS — unnecessary complexity
- YAGNI — speculative code not needed now
- Minor readability improvements

### 4. Format the response

The response MUST follow this structure:

```
## [SUMMARY]
Brief quality assessment (1-3 sentences). Overall verdict: ✅ Ready to merge / ⚠️ Needs fixes / 🚫 Blockers to resolve.

## [BLOCKERS / CRITICAL ISSUES] 🔴
> Omit section if none.

Each blocker as a separate item:
- **File:Line** — Problem description
  - *Why it's a problem:* brief explanation
  - *Fix:* corrected code snippet

## [ARCHITECTURAL NOTES / CLEAN CODE] 🟡
> Omit section if none.

- **File:Line** — Code smell / violation description
  - *Principle:* SOLID/DRY/SRP/etc.
  - *Explanation:* why this is a problem

## [SUGGESTIONS & CODE] 🟢
> Omit section if none.

- **File:Line** — Improvement proposal
  - Corrected code snippet (if applicable)
```

### 5. Review guidelines

- **Be direct, objective, and professional.** Don't sugarcoat.
- **Mentor role:** when pointing out an issue, explain *why* the approach is wrong and show a better one.
- **Architectural context:** evaluate changes in the context of the project's overall architecture, not in isolation.
- **Don't demand perfection:** suggestions (🟢) are proposals, not requirements. Blockers (🔴) are the only hard requirements.
- **Acknowledge good solutions:** if you see an elegant approach, mention it briefly.
- **Response language: Polish.**

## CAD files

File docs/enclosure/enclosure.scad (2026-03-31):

// ============================================================
// Obudowa IoT Access Control — ESP8266 (Wemos D1 Mini) + PN532 NFC/RFID
// Parametryczny model OpenSCAD
// ============================================================
// Użycie z terminala:
//   Podgląd:  openscad enclosure.scad
//   Eksport:  openscad -o enclosure_bottom.stl -D "part=\"bottom\"" enclosure.scad
//             openscad -o enclosure_top.stl    -D "part=\"top\""    enclosure.scad
//             openscad -o enclosure_all.stl    -D "part=\"assembled\"" enclosure.scad
// ============================================================

/* [Wybór części do renderowania] */
part = "assembled"; // ["bottom", "top", "assembled", "exploded"]

/* [Tolerancje druku 3D] */
tol        = 0.3;   // tolerancja wymiaru (mm)
wall       = 2.0;   // grubość ścianki ogólna (mm)
nfc_wall   = 1.5;   // grubość ścianki nad anteną NFC (mm) — max 2mm!
corner_r   = 3.0;   // promień zaokrąglenia narożników

/* [Wemos D1 Mini — ESP8266] */
wemos_l    = 34.5;  // długość PCB
wemos_w    = 25.4;  // szerokość PCB
wemos_pcb  = 1.6;   // grubość PCB
wemos_h    = 6.0;   // profil Z (z komponentami, bez goldpinów)
wemos_usb_w = 11.0; // szerokość otworu USB
wemos_usb_h = 7.0;  // wysokość otworu USB
wemos_reset_d = 2.0;// średnica otworu na reset

/* [PN532 NFC/RFID V3] */
pn532_l    = 42.7;  // długość PCB
pn532_w    = 40.4;  // szerokość PCB
pn532_pcb  = 1.6;   // grubość PCB
pn532_h    = 4.0;   // profil Z komponentów (bez pinów)
pn532_hole_d = 2.2; // średnica otworów montażowych (M2 + luz)
pn532_hole_offset = 2.5; // odległość otworu od krawędzi

/* [Śruby montażowe PN532] */
screw_d      = 2.0;   // M2 gwint
standoff_d   = 4.5;   // średnica słupka
standoff_h   = 3.0;   // wysokość słupka (dystans PCB od dna)

/* [Parametry wewnętrzne] */
cable_channel_w = 8;  // szerokość kanału na przewody
cable_channel_h = 5;  // wysokość kanału na przewody
vent_slot_w     = 1.5;// szerokość szczeliny wentylacyjnej
vent_slot_l     = 12; // długość szczeliny wentylacyjnej
vent_count      = 4;  // ilość szczelin

// ============================================================
// OBLICZENIA AUTOMATYCZNE
// ============================================================

// Wewnętrzne wymiary — PN532 dominuje szerokość
inner_w = max(pn532_w, wemos_w) + 2 * tol + cable_channel_w;
inner_l = pn532_l + 2 * tol + 4; // zapas na kable i montaż
inner_h_bottom = standoff_h + pn532_pcb + pn532_h + 2; // sekcja dolna (PN532 + Wemos)
inner_h_top    = standoff_h + wemos_pcb + wemos_h + 2;  // sekcja górna

// Łączna wysokość wnętrza
inner_h = inner_h_bottom + inner_h_top + cable_channel_h;

// Zewnętrzne wymiary
outer_w = inner_w + 2 * wall;
outer_l = inner_l + 2 * wall;
outer_h_bottom = inner_h * 0.6 + wall; // 60% dół
outer_h_top    = inner_h * 0.4 + nfc_wall; // 40% góra (z cienką ścianką NFC)
outer_h = outer_h_bottom + outer_h_top;

// Lip (zamek zatrzaskowy góra-dół)
lip_h     = 2.0;
lip_thick = 1.2;

// Pozycje modułów wewnątrz
wemos_x = wall + tol + 2;
wemos_y = wall + tol + (inner_w - wemos_w) / 2;
wemos_z = wall + standoff_h;

pn532_x = wall + tol + (inner_l - pn532_l) / 2;
pn532_y = wall + tol + (inner_w - pn532_w) / 2;
pn532_z_in_top = outer_h_top - nfc_wall - pn532_pcb - tol; // blisko górnej ścianki

// ============================================================
// MODUŁY POMOCNICZE
// ============================================================

module rounded_box(size, r) {
    // Prostopadłościan z zaokrąglonymi narożnikami w XY
    hull() {
        for (x = [r, size[0] - r])
            for (y = [r, size[1] - r])
                translate([x, y, 0])
                    cylinder(r = r, h = size[2], $fn = 32);
    }
}

module rounded_box_hollow(outer, wall_t, r) {
    difference() {
        rounded_box(outer, r);
        translate([wall_t, wall_t, wall_t])
            rounded_box([outer[0] - 2*wall_t, 
                         outer[1] - 2*wall_t, 
                         outer[2]], r - wall_t/2);
    }
}

// Słupek montażowy z otworem na śrubę
module standoff(h, outer_d, inner_d) {
    difference() {
        cylinder(d = outer_d, h = h, $fn = 24);
        translate([0, 0, -0.1])
            cylinder(d = inner_d, h = h + 0.2, $fn = 24);
    }
}

// Prowadnica szynowa do trzymania PCB bez otworów montażowych
module pcb_rail(length, pcb_thick, depth) {
    // Szyna w kształcie litery L
    cube([length, depth, pcb_thick + tol]);
    cube([length, 1.2, pcb_thick + tol + 2]);
}

// Szczeliny wentylacyjne
module vent_slots(count, slot_l, slot_w, wall_t) {
    spacing = (slot_l + 3);
    for (i = [0 : count - 1]) {
        translate([i * spacing, 0, 0])
            cube([slot_l, wall_t + 0.2, slot_w]);
    }
}

// Symbol NFC na obudowie (wytłoczenie)
module nfc_symbol(size) {
    // Uproszczony symbol "fal" NFC
    line_w = 0.8;
    for (i = [0 : 2]) {
        r = size * 0.3 + i * size * 0.15;
        difference() {
            cylinder(r = r + line_w/2, h = 0.6, $fn = 48);
            translate([0, 0, -0.1])
                cylinder(r = r - line_w/2, h = 0.8, $fn = 48);
            // Wytnij 3/4 okręgu — zostaw ćwiartkę
            translate([-r*2, -r*2, -0.1])
                cube([r*2, r*4, 1]);
            translate([-r*2, -r*2, -0.1])
                cube([r*4, r*2, 1]);
        }
    }
    // Kropka w centrum
    cylinder(d = size * 0.15, h = 0.6, $fn = 24);
}

// ============================================================
// DOLNA POŁOWA OBUDOWY (BOTTOM)
// ============================================================

module bottom_case() {
    difference() {
        union() {
            // Główna skorupa
            rounded_box_hollow([outer_l, outer_w, outer_h_bottom], wall, corner_r);
            
            // Lip (krawędź do zamknięcia) — wewnętrzna krawędź
            translate([wall - lip_thick, wall - lip_thick, outer_h_bottom - 0.01])
                difference() {
                    rounded_box([outer_l - 2*(wall - lip_thick), 
                                 outer_w - 2*(wall - lip_thick), 
                                 lip_h], corner_r);
                    translate([lip_thick, lip_thick, -0.1])
                        rounded_box([outer_l - 2*wall, 
                                     outer_w - 2*wall, 
                                     lip_h + 0.2], corner_r - lip_thick);
                }
        }
        
        // ---- OTWÓR NA USB (Wemos D1 Mini) — boczna ściana ----
        translate([-0.1, 
                   wemos_y + (wemos_w - wemos_usb_w) / 2,
                   wemos_z + wemos_pcb])
            cube([wall + 0.2, wemos_usb_w, wemos_usb_h]);
        
        // ---- OTWÓR NA PRZYCISK RESET ----
        translate([-0.1,
                   wemos_y + wemos_w * 0.3,  // obok USB
                   wemos_z + wemos_pcb + 2])
            rotate([0, 90, 0])
                cylinder(d = wemos_reset_d, h = wall + 0.2, $fn = 16);
        
        // ---- SZCZELINY WENTYLACYJNE — dno ----
        total_vent_l = vent_count * (vent_slot_l + 3);
        translate([(outer_l - total_vent_l) / 2,
                   (outer_w - vent_slot_w) / 2,
                   -0.1])
            vent_slots(vent_count, vent_slot_l, vent_slot_w, wall);
        
        // ---- SZCZELINY WENTYLACYJNE — boki ----
        for (side = [0, 1]) {
            translate([(outer_l - total_vent_l) / 2,
                       side * (outer_w - wall) - 0.1,
                       outer_h_bottom * 0.3])
                vent_slots(vent_count, vent_slot_l, vent_slot_w, wall);
        }
    }
    
    // ---- PROWADNICE SZYNOWE DLA WEMOS D1 MINI ----
    // Dwie szyny po bokach trzymające PCB 1.6mm
    translate([wemos_x, wemos_y - 1.5, wemos_z])
        pcb_rail(wemos_l, wemos_pcb, 1.5);
    translate([wemos_x, wemos_y + wemos_w + 0.3, wemos_z])
        mirror([0, 1, 0])
            pcb_rail(wemos_l, wemos_pcb, 1.5);
    
    // ---- KANAŁ NA PRZEWODY ----
    // Pionowy kanał łączący sekcję Wemos z sekcją PN532 (góra)
    // (zostawiony jako wolna przestrzeń — nie musi być osobnym elementem)
}

// ============================================================
// GÓRNA POŁOWA OBUDOWY (TOP / POKRYWA)
// ============================================================

// Chamfered standoff — faza 45° u podstawy dla drukowalności
module standoff_chamfered(h, outer_d, inner_d, chamfer = 0.8) {
    difference() {
        union() {
            // Faza 45° (stożek u podstawy)
            cylinder(d1 = outer_d + 2*chamfer, d2 = outer_d, h = chamfer, $fn = 24);
            // Główny cylinder
            translate([0, 0, chamfer - 0.01])
                cylinder(d = outer_d, h = h - chamfer + 0.01, $fn = 24);
        }
        // Otwór na śrubę
        translate([0, 0, -0.1])
            cylinder(d = inner_d, h = h + 0.2, $fn = 24);
    }
}

// Przejście schodkowe (chamfer) między strefą grubą a cienką NFC
nfc_chamfer = 0.8; // mm — łagodne przejście
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

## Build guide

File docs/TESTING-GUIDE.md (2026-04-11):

# Testy Jednostkowe — Przewodnik

## Spis treści

1. [Struktura projektów testowych](#1-struktura-projektów-testowych)
2. [Tworzenie projektów testowych](#2-tworzenie-projektów-testowych)
3. [Konwencje nazewnicze](#3-konwencje-nazewnicze)
4. [Testy encji domenowych (bez mockowania)](#4-testy-encji-domenowych-bez-mockowania)
5. [Testy walidatorów FluentValidation](#5-testy-walidatorów-fluentvalidation)
6. [Testy handlerów CQRS (z NSubstitute)](#6-testy-handlerów-cqrs-z-nsubstitute)
7. [Testy query handlerów](#7-testy-query-handlerów)
8. [Testy metod pomocniczych (MqttTopics)](#8-testy-metod-pomocniczych-mqtttopics)
9. [Uruchamianie testów](#9-uruchamianie-testów)
10. [Wskazówki i dobre praktyki](#10-wskazówki-i-dobre-praktyki)

---

## 1. Struktura projektów testowych

```
tests/
  AccessControl.Domain.Tests/          ← testy encji i value objects (ZERO zależności)
    AccessControl.Domain.Tests.csproj
    Entities/
      AccessCardTests.cs
      AccessZoneTests.cs
      DeviceTests.cs
      ...
    ValueObjects/
      DiscoveredDeviceInfoTests.cs

  AccessControl.Application.Tests/     ← testy handlerów, walidatorów, utilsów
    AccessControl.Application.Tests.csproj
    Cards/
      CreateAccessCardCommandValidatorTests.cs
      CreateAccessCardCommandHandlerTests.cs
      GetAccessCardsQueryHandlerTests.cs
    Common/
      MqttTopicsTests.cs
    ...
```

**Zasada**: struktura folderów w testach odzwierciedla strukturę kodu źródłowego.

---

## 2. Tworzenie projektów testowych

### Krok 1 — Domain Tests

```bash
cd c:\Users\patcz\Desktop\iot

# Utwórz projekt testowy
dotnet new xunit -o tests/AccessControl.Domain.Tests -f net10.0

# Dodaj referencję do testowanego projektu
dotnet add tests/AccessControl.Domain.Tests reference src/AccessControl.Domain

# Dodaj FluentAssertions
dotnet add tests/AccessControl.Domain.Tests package FluentAssertions

# Dodaj do solution
dotnet sln add tests/AccessControl.Domain.Tests --solution-folder tests
```

### Krok 2 — Application Tests

```bash
dotnet new xunit -o tests/AccessControl.Application.Tests -f net10.0

dotnet add tests/AccessControl.Application.Tests reference src/AccessControl.Application
dotnet add tests/AccessControl.Application.Tests reference src/AccessControl.Domain

# Pakiety
dotnet add tests/AccessControl.Application.Tests package FluentAssertions
dotnet add tests/AccessControl.Application.Tests package NSubstitute
dotnet add tests/AccessControl.Application.Tests package FluentValidation.TestHelper

dotnet sln add tests/AccessControl.Application.Tests --solution-folder tests
```

### Krok 3 — Weryfikacja

```bash
dotnet build tests/
```

---

## 3. Konwencje nazewnicze

### Format nazwy testu

```
NazwaMetody_Scenariusz_OczekiwanyRezultat
```

Przykłady:
- `Create_WithValidUid_ReturnsCardWithNormalizedUid`
- `Create_WithEmptyUid_ThrowsArgumentException`
- `UpdateConfiguration_WithInvalidKey_ThrowsDomainValidationException`

### Wzorzec AAA (Arrange → Act → Assert)

Każdy test dzielimy na 3 sekcje:

```csharp
[Fact]
public void Create_WithValidUid_ReturnsCardWithNormalizedUid()
{
    // Arrange — przygotuj dane wejściowe
    var uid = "ab:cd:ef:12";

    // Act — wywołaj testowaną metodę
    var card = AccessCard.Create(uid);

    // Assert — sprawdź wynik
    card.CardUid.Should().Be("AB:CD:EF:12");
}
```

---

## 4. Testy encji domenowych (bez mockowania)

Testy domenowe to najlepszy punkt startowy — nie wymagają żadnego mockowania, testują czystą logikę biznesową.

### Pełny przykład: `AccessCardTests.cs`

```csharp
using AccessControl.Domain.Entities;
using FluentAssertions;

namespace AccessControl.Domain.Tests.Entities;

public class AccessCardTests
{
    // ── Create ──────────────────────────────────────────────

    [Fact]
    public void Create_WithValidUid_ReturnsCardWithCorrectProperties()
    {
        // Arrange
        var uid = "ab:cd:ef:12";
        var label = "Karta wejściowa";

        // Act
        var card = AccessCard.Create(uid, label);

        // Assert
        card.Id.Should().NotBeEmpty();
        card.CardUid.Should().Be("AB:CD:EF:12");   // znormalizowany do uppercase
        card.Label.Should().Be("Karta wejściowa");
        card.IsActive.Should().BeTrue();            // domyślnie aktywna
        card.CardholderId.Should().BeNull();        // brak przypisanego właściciela
        card.CreatedAt.Should().BeCloseTo(DateTime.UtcNow, TimeSpan.FromSeconds(1));
    }

    [Theory]
    [InlineData(null)]
    [InlineData("")]
    [InlineData("   ")]
    public void Create_WithEmptyUid_ThrowsArgumentException(string? uid)
    {
        // Act
        var act = () => AccessCard.Create(uid!);

        // Assert
        act.Should().Throw<ArgumentException>();
    }

    [Fact]
    public void Create_WithLabel_TrimsWhitespace()
    {
        // Act
        var card = AccessCard.Create("AABB", "  Main door  ");

        // Assert
        card.Label.Should().Be("Main door");
    }

    [Fact]
    public void Create_WithNullLabel_SetsLabelToNull()
    {
        // Act
        var card = AccessCard.Create("AABB");

        // Assert
        card.Label.Should().BeNull();
    }

    // ── NormalizeUid ────────────────────────────────────────

    [Theory]
    [InlineData("ab:cd:ef", "AB:CD:EF")]
    [InlineData("  AB:CD  ", "AB:CD")]
    [InlineData("aAbBcC", "AABBCC")]
    public void NormalizeUid_VariousInputs_ReturnsUppercaseTrimmed(string input, string expected)
    {
        // Act
        var result = AccessCard.NormalizeUid(input);

        // Assert
        result.Should().Be(expected);
    }

    // ── AssignCardholder ────────────────────────────────────

    [Fact]
    public void AssignCardholder_WithValidId_SetsCardholderId()
    {
        // Arrange
        var card = AccessCard.Create("AABB");
        var cardholderId = Guid.NewGuid();

        // Act
        card.AssignCardholder(cardholderId);

        // Assert
        card.CardholderId.Should().Be(cardholderId);
    }

    [Fact]
    public void AssignCardholder_WithEmptyGuid_ThrowsArgumentException()
    {
        // Arrange
        var card = AccessCard.Create("AABB");

        // Act
        var act = () => card.AssignCardholder(Guid.Empty);

        // Assert
        act.Should().Throw<ArgumentException>()
            .WithMessage("*cannot be empty*");
    }

    // ── UnassignCardholder ──────────────────────────────────

    [Fact]
    public void UnassignCardholder_WhenAssigned_ClearsCardholderId()
    {
        // Arrange
        var card = AccessCard.Create("AABB");
        card.AssignCardholder(Guid.NewGuid());

        // Act
        card.UnassignCardholder();

        // Assert
        card.CardholderId.Should().BeNull();
    }

    // ── Update ──────────────────────────────────────────────

    [Fact]
    public void Update_WithNewValues_UpdatesLabelAndIsActive()
    {
        // Arrange
        var card = AccessCard.Create("AABB", "Old label");

        // Act
        card.Update("New label", false);

        // Assert
        card.Label.Should().Be("New label");
        card.IsActive.Should().BeFalse();
        card.UpdatedAt.Should().BeCloseTo(DateTime.UtcNow, TimeSpan.FromSeconds(1));
    }

    // ── Deactivate ──────────────────────────────────────────

    [Fact]
    public void Deactivate_WhenActive_SetsIsActiveToFalse()
    {
        // Arrange
        var card = AccessCard.Create("AABB");
        card.IsActive.Should().BeTrue(); // warunek wstępny

        // Act
        card.Deactivate();

        // Assert
        card.IsActive.Should().BeFalse();
    }
}
```

### Pełny przykład: `AccessZoneTests.cs`

```csharp
using AccessControl.Domain.Entities;
using AccessControl.Domain.Exceptions;
using FluentAssertions;

namespace AccessControl.Domain.Tests.Entities;

public class AccessZoneTests
{
    [Fact]
    public void Create_WithValidName_ReturnsZone()
    {
        // Act
        var zone = AccessZone.Create("Strefa A", "Główne wejście");

        // Assert
        zone.Name.Should().Be("Strefa A");
        zone.Description.Should().Be("Główne wejście");
    }

    [Fact]
    public void Create_WithNameExceeding100Chars_ThrowsDomainValidationException()
    {
        // Arrange
        var longName = new string('x', 101);

        // Act
        var act = () => AccessZone.Create(longName);

        // Assert
        act.Should().Throw<DomainValidationException>()
            .WithMessage("*cannot exceed 100*");
    }

    [Fact]
    public void Create_WithDescriptionExceeding500Chars_ThrowsDomainValidationException()
    {
        // Arrange
        var longDesc = new string('x', 501);

        // Act
        var act = () => AccessZone.Create("OK", longDesc);

        // Assert
        act.Should().Throw<DomainValidationException>()
            .WithMessage("*cannot exceed 500*");
    }

    [Fact]
    public void UpdateName_WithValidName_UpdatesNameAndTimestamp()
    {
        // Arrange
        var zone = AccessZone.Create("Old");
        var beforeUpdate = zone.UpdatedAt;

        // Act
        zone.UpdateName("New");

        // Assert
        zone.Name.Should().Be("New");
        zone.UpdatedAt.Should().BeOnOrAfter(beforeUpdate);
    }

    [Fact]
    public void UpdateDescription_WithNull_ClearsDescription()
    {
        // Arrange
        var zone = AccessZone.Create("Zone", "Some description");

        // Act
        zone.UpdateDescription(null);

        // Assert
        zone.Description.Should().BeNull();
    }
}
```

### Pełny przykład: `DeviceTests.cs` (bardziej złożona encja)

```csharp
using AccessControl.Domain.Entities;
using AccessControl.Domain.Enums;
using AccessControl.Domain.Exceptions;
using FluentAssertions;

namespace AccessControl.Domain.Tests.Entities;

public class DeviceTests
{
    // Helper — tworzy prawidłowe urządzenie do użycia w testach
    private static Device CreateValidDevice() => Device.Create(
        name: "Card Reader 1",
        zoneId: Guid.NewGuid(),
        hardwareId: Guid.NewGuid(),
        adapterType: DeviceAdapterType.CardReader,
        features: DeviceFeatures.CardReader);

    // ── Create ──────────────────────────────────────────────

    [Fact]
    public void Create_WithValidInput_ReturnsDevice()
    {
        // Act
        var device = CreateValidDevice();

        // Assert
        device.Id.Should().NotBeEmpty();
        device.Name.Should().Be("Card Reader 1");
        device.Status.Should().Be(DeviceStatus.Offline); // domyślnie offline
        device.LastHeartbeat.Should().BeNull();
        device.Configuration.Should().BeEmpty();
    }

    [Fact]
    public void Create_WithEmptyZoneId_ThrowsDomainValidationException()
    {
        // Act
        var act = () => Device.Create("Reader", Guid.Empty, Guid.NewGuid(),
            DeviceAdapterType.CardReader, DeviceFeatures.CardReader);

        // Assert
        act.Should().Throw<DomainValidationException>()
            .WithMessage("*ZoneId*");
    }

    // ── RecordHeartbeat ─────────────────────────────────────

    [Fact]
    public void RecordHeartbeat_WhenOffline_SetsStatusToOnline()
    {
        // Arrange
        var device = CreateValidDevice();
        device.Status.Should().Be(DeviceStatus.Offline);

        // Act
        device.RecordHeartbeat();

        // Assert
        device.Status.Should().Be(DeviceStatus.Online);
        device.LastHeartbeat.Should().BeCloseTo(DateTime.UtcNow, TimeSpan.FromSeconds(1));
    }

    // ── UpdateConfiguration ─────────────────────────────────

    [Fact]
    public void UpdateConfiguration_WithValidSettings_UpdatesValues()
    {
        // Arrange
        var device = CreateValidDevice();

        // Act
        device.UpdateConfiguration(new Dictionary<string, string>
        {
            ["buzzerEnabled"] = "true",
            ["ledBrightness"] = "128"
        });

        // Assert
        device.Configuration.Should().ContainKey("buzzerEnabled").WhoseValue.Should().Be("true");
        device.Configuration.Should().ContainKey("ledBrightness").WhoseValue.Should().Be("128");
    }

    [Fact]
    public void UpdateConfiguration_WithInvalidKey_ThrowsDomainValidationException()
    {
        // Arrange
        var device = CreateValidDevice();

        // Act
        var act = () => device.UpdateConfiguration(new Dictionary<string, string>
        {
            ["nonExistentKey"] = "value"
        });

        // Assert
        act.Should().Throw<DomainValidationException>()
            .WithMessage("*Invalid configuration keys*nonExistentKey*");
    }

    [Fact]
    public void UpdateConfiguration_WithInvalidValue_ThrowsDomainValidationException()
    {
        // Arrange
        var device = CreateValidDevice();

        // Act — ledBrightness musi być 0-255, "999" jest poza zakresem
        var act = () => device.UpdateConfiguration(new Dictionary<string, string>
        {
            ["ledBrightness"] = "999"
        });

        // Assert
        act.Should().Throw<DomainValidationException>()
            .WithMessage("*Invalid configuration values*");
    }
}
```

---

## 5. Testy walidatorów FluentValidation

FluentValidation dostarcza specjalny pakiet `FluentValidation.TestHelper` z metodami `.TestValidate()` i `.ShouldHaveValidationErrorFor()`.

### Przykład: `CreateAccessCardCommandValidatorTests.cs`

```csharp
using AccessControl.Application.Cards.Commands;
using FluentValidation.TestHelper;

namespace AccessControl.Application.Tests.Cards;

public class CreateAccessCardCommandValidatorTests
{
    // Tworzymy JEDNĄ instancję walidatora — jest bezstanowy
    private readonly CreateAccessCardCommandValidator _validator = new();

    // ── CardUid ─────────────────────────────────────────────

    [Fact]
    public void Validate_WithEmptyCardUid_HasError()
    {
        // Arrange
        var command = new CreateAccessCardCommand("", null, null);

        // Act
        var result = _validator.TestValidate(command);

        // Assert
        result.ShouldHaveValidationErrorFor(x => x.CardUid);
    }

    [Fact]
    public void Validate_WithCardUidExceeding20Chars_HasError()
    {
        // Arrange
        var command = new CreateAccessCardCommand(new string('A', 21), null, null);

        // Act
        var result = _validator.TestValidate(command);

        // Assert
        result.ShouldHaveValidationErrorFor(x => x.CardUid);
    }

    [Fact]
    public void Validate_WithValidCardUid_HasNoError()
    {
        // Arrange
        var command = new CreateAccessCardCommand("AABBCCDD", null, null);

        // Act
        var result = _validator.TestValidate(command);

        // Assert
        result.ShouldNotHaveValidationErrorFor(x => x.CardUid);
    }

    // ── CardholderId ────────────────────────────────────────

    [Fact]
    public void Validate_WithEmptyCardholderId_HasError()
    {
        // Arrange — Guid.Empty jest niedozwolony jeśli jest podany
        var command = new CreateAccessCardCommand("AABB", Guid.Empty, null);

        // Act
        var result = _validator.TestValidate(command);

        // Assert
        result.ShouldHaveValidationErrorFor(x => x.CardholderId);
    }

    [Fact]
    public void Validate_WithNullCardholderId_HasNoError()
    {
        // Arrange — null jest OK (karta bez właściciela)
        var command = new CreateAccessCardCommand("AABB", null, null);

        // Act
        var result = _validator.TestValidate(command);

        // Assert
        result.ShouldNotHaveValidationErrorFor(x => x.CardholderId);
    }

    // ── Label ───────────────────────────────────────────────

    [Fact]
    public void Validate_WithLabelExceeding200Chars_HasError()
    {
        // Arrange
        var command = new CreateAccessCardCommand("AABB", null, new string('x', 201));

        // Act
        var result = _validator.TestValidate(command);

        // Assert
        result.ShouldHaveValidationErrorFor(x => x.Label);
    }

    // ── Pełna walidacja ─────────────────────────────────────

    [Fact]
    public void Validate_WithAllValidFields_HasNoErrors()
    {
        // Arrange
        var command = new CreateAccessCardCommand("AABBCCDD", Guid.NewGuid(), "Main entrance");

        // Act
        var result = _validator.TestValidate(command);

        // Assert
        result.ShouldNotHaveAnyValidationErrors();
    }
}
```

---

## 6. Testy handlerów CQRS (z NSubstitute)

Handlery mają zależności (repozytoria, serwisy) — mockujemy je za pomocą **NSubstitute**.

### Kluczowe koncepcje NSubstitute

```csharp
// Tworzenie mocka
var repo = Substitute.For<IAccessCardRepository>();

// Konfiguracja zwracanej wartości
repo.ExistsByCardUidAsync("AABB", Arg.Any<CancellationToken>())
    .Returns(false);

// Weryfikacja, że metoda została wywołana
await repo.Received(1).AddAsync(Arg.Any<AccessCard>(), Arg.Any<CancellationToken>());

// Weryfikacja, że metoda NIE została wywołana
await repo.DidNotReceive().SaveChangesAsync(Arg.Any<CancellationToken>());
```

### Pełny przykład: `CreateAccessCardCommandHandlerTests.cs`

```csharp
using AccessControl.Application.Cards.Commands;
using AccessControl.Application.Common.Interfaces;
using AccessControl.Domain.Entities;
using AccessControl.Domain.Exceptions;
using FluentAssertions;
using NSubstitute;

namespace AccessControl.Application.Tests.Cards;

public class CreateAccessCardCommandHandlerTests
{
    // Zależności (mocki)
    private readonly IAccessCardRepository _cardRepository = Substitute.For<IAccessCardRepository>();
    private readonly ICardholderRepository _cardholderRepository = Substitute.For<ICardholderRepository>();

    // System under test (SUT) — testowany handler
    private readonly CreateAccessCardCommandHandler _sut;

    public CreateAccessCardCommandHandlerTests()
    {
        // Wstrzykujemy mocki do handlera
        _sut = new CreateAccessCardCommandHandler(_cardRepository, _cardholderRepository);
    }

    // ── Happy path ──────────────────────────────────────────

    [Fact]
    public async Task Handle_WithNewCardUid_CreatesCardAndReturnsId()
    {
        // Arrange
        var command = new CreateAccessCardCommand("aabb", null, "Test card");

        _cardRepository.ExistsByCardUidAsync("AABB", Arg.Any<CancellationToken>())
            .Returns(false);

        // Act
        var result = await _sut.Handle(command, CancellationToken.None);

        // Assert
        result.Should().NotBeEmpty(); // zwrócony Guid

        // Sprawdź, że karta została dodana do repozytorium
        await _cardRepository.Received(1)
            .AddAsync(Arg.Is<AccessCard>(c =>
                c.CardUid == "AABB" &&          // UID znormalizowany
                c.Label == "Test card" &&
                c.IsActive == true),
                Arg.Any<CancellationToken>());

        // Sprawdź, że zmiany zostały zapisane
        await _cardRepository.Received(1)
            .SaveChangesAsync(Arg.Any<CancellationToken>());
    }

    // ── Duplikat UID ────────────────────────────────────────

    [Fact]
    public async Task Handle_WithDuplicateUid_ThrowsBusinessRuleException()
    {
        // Arrange
        var command = new CreateAccessCardCommand("AABB", null, null);

        _cardRepository.ExistsByCardUidAsync("AABB", Arg.Any<CancellationToken>())
            .Returns(true);  // ← karta już istnieje!

        // Act
        var act = () => _sut.Handle(command, CancellationToken.None);

        // Assert
        await act.Should().ThrowAsync<BusinessRuleException>()
            .WithMessage("*already registered*");

        // Upewnij się, że NIE próbowano zapisać
        await _cardRepository.DidNotReceive()
            .AddAsync(Arg.Any<AccessCard>(), Arg.Any<CancellationToken>());
    }

    // ── Z istniejącym cardholderem ──────────────────────────

    [Fact]
    public async Task Handle_WithValidCardholderId_AssignsCardholder()
    {
        // Arrange
        var cardholderId = Guid.NewGuid();
        var command = new CreateAccessCardCommand("AABB", cardholderId, null);

        _cardRepository.ExistsByCardUidAsync("AABB", Arg.Any<CancellationToken>())
            .Returns(false);

        // Symuluj istniejącego cardholdera
        var cardholder = Cardholder.Create("Jan", "Kowalski");
        _cardholderRepository.GetByIdAsync(cardholderId, Arg.Any<CancellationToken>())
            .Returns(cardholder);

        // Act
        var result = await _sut.Handle(command, CancellationToken.None);

        // Assert
        result.Should().NotBeEmpty();

        await _cardRepository.Received(1)
            .AddAsync(Arg.Is<AccessCard>(c => c.CardholderId == cardholder.Id),
                Arg.Any<CancellationToken>());
    }

    // ── Z nieistniejącym cardholderem ───────────────────────

    [Fact]
    public async Task Handle_WithNonExistentCardholderId_ThrowsKeyNotFoundException()
    {
        // Arrange
        var cardholderId = Guid.NewGuid();
        var command = new CreateAccessCardCommand("AABB", cardholderId, null);

        _cardRepository.ExistsByCardUidAsync("AABB", Arg.Any<CancellationToken>())
            .Returns(false);

        _cardholderRepository.GetByIdAsync(cardholderId, Arg.Any<CancellationToken>())
            .Returns((Cardholder?)null);  // ← nie znaleziono!

        // Act
        var act = () => _sut.Handle(command, CancellationToken.None);

        // Assert
        await act.Should().ThrowAsync<KeyNotFoundException>()
            .WithMessage($"*{cardholderId}*");
    }
}
```

---

## 7. Testy query handlerów

Query handlery są prostsze — sprawdzamy mapowanie encji na DTO.

### Przykład: `GetAccessCardsQueryHandlerTests.cs`

```csharp
using AccessControl.Application.Cards.DTOs;
using AccessControl.Application.Cards.Queries;
using AccessControl.Application.Common.Interfaces;
using AccessControl.Domain.Entities;
using FluentAssertions;
using NSubstitute;

namespace AccessControl.Application.Tests.Cards;

public class GetAccessCardsQueryHandlerTests
{
    private readonly IAccessCardRepository _repository = Substitute.For<IAccessCardRepository>();
    private readonly GetAccessCardsQueryHandler _sut;

    public GetAccessCardsQueryHandlerTests()
    {
        _sut = new GetAccessCardsQueryHandler(_repository);
    }

    [Fact]
    public async Task Handle_WithCards_ReturnsMappedDtos()
    {
        // Arrange
        var card = AccessCard.Create("AABB", "Test");

        _repository.GetAllAsync(Arg.Any<CancellationToken>())
            .Returns(new[] { card });

        // Act
        var result = await _sut.Handle(new GetAccessCardsQuery(), CancellationToken.None);

        // Assert
        result.Should().HaveCount(1);

        var dto = result.First();
        dto.CardUid.Should().Be("AABB");
        dto.Label.Should().Be("Test");
        dto.IsActive.Should().BeTrue();
        dto.CardholderId.Should().BeNull();
        dto.CardholderName.Should().BeNull();
    }

    [Fact]
    public async Task Handle_WithNoCards_ReturnsEmptyCollection()
    {
        // Arrange
        _repository.GetAllAsync(Arg.Any<CancellationToken>())
            .Returns(Array.Empty<AccessCard>());

        // Act
        var result = await _sut.Handle(new GetAccessCardsQuery(), CancellationToken.None);

        // Assert
        result.Should().BeEmpty();
    }
}
```

---

## 8. Testy metod pomocniczych (MqttTopics)

Statyczne utility classes testuje się bez mockowania — czyste wejście → czyste wyjście.

### Przykład: `MqttTopicsTests.cs`

```csharp
using AccessControl.Application.Common;
using FluentAssertions;

namespace AccessControl.Application.Tests.Common;

public class MqttTopicsTests
{
    // ── TryExtractHardwareId ────────────────────────────────

    [Fact]
    public void TryExtractHardwareId_WithValidTopic_ReturnsTrueAndExtractsGuid()
    {
        // Arrange
        var hwid = Guid.NewGuid();
        var topic = $"accesscontrol/{hwid}/card/scanned";

        // Act
        var result = MqttTopics.TryExtractHardwareId(topic, out var extracted);

        // Assert
        result.Should().BeTrue();
        extracted.Should().Be(hwid);
    }

    [Theory]
    [InlineData("invalid/topic")]
    [InlineData("accesscontrol/not-a-guid/card")]
    [InlineData("")]
    public void TryExtractHardwareId_WithInvalidTopic_ReturnsFalse(string topic)
    {
        // Act
        var result = MqttTopics.TryExtractHardwareId(topic, out var extracted);

        // Assert
        result.Should().BeFalse();
        extracted.Should().Be(Guid.Empty);
    }

    // ── Topic builders ──────────────────────────────────────

    [Fact]
    public void CardEnroll_ReturnsCorrectTopic()
    {
        // Arrange
        var hwid = Guid.Parse("11111111-2222-3333-4444-555555555555");

        // Act
        var topic = MqttTopics.CardEnroll(hwid);

        // Assert
        topic.Should().Be("accesscontrol/11111111-2222-3333-4444-555555555555/card/enroll");
    }

    [Fact]
    public void LockCommand_ReturnsCorrectTopic()
    {
        var hwid = Guid.NewGuid();

        var topic = MqttTopics.LockCommand(hwid);

        topic.Should().StartWith("accesscontrol/")
             .And.EndWith("/lock/command");
    }

    // ── Subscribe patterns ──────────────────────────────────

    [Fact]
    public void SubscribePatterns_ContainsExpectedTopics()
    {
        MqttTopics.SubscribePatterns.Should().Contain(p => p.Contains("heartbeat"));
        MqttTopics.SubscribePatterns.Should().Contain(p => p.Contains("card/scanned"));
        MqttTopics.SubscribePatterns.Should().Contain(p => p.Contains("announce"));
    }
}
```

---

## 9. Uruchamianie testów

### Z terminala

```bash
# Wszystkie testy
dotnet test tests/

# Tylko testy domenowe
dotnet test tests/AccessControl.Domain.Tests/

# Tylko testy aplikacji
dotnet test tests/AccessControl.Application.Tests/

# Z większą ilością szczegółów
dotnet test tests/ --verbosity normal

# Filtrowanie po nazwie testu
dotnet test tests/ --filter "AccessCardTests"

# Filtrowanie po pełnej nazwie
dotnet test tests/ --filter "FullyQualifiedName~Create_WithValidUid"
```

### Z VS Code

Jeśli masz zainstalowane **C# Dev Kit**, testy pojawią się w panelu **Test Explorer** (ikona kolby po lewej stronie). Możesz tam:
- Uruchamiać pojedyncze testy klikając ▶
- Uruchamiać wszystkie testy w klasie
- Debugować testy z breakpointami

---

## 10. Wskazówki i dobre praktyki

### Co testować, a czego nie

| ✅ Testuj | ❌ Nie testuj |
|---|---|
| Logika biznesowa w encjach | Gettery/settery bez logiki |
| Factory methods (`Create()`) | Frameworki (EF Core, MediatR) |
| Walidatory FluentValidation | Prywatne pola/metody |
| Handlery CQRS (logika w `Handle()`) | Konfigurację DI |
| Metody statyczne z logiką | Proste mapowania bez warunków |
| Rzucanie wyjątków przy błędnych danych | Kod infrastrukturalny (baza danych) |

### Atrybuty xUnit

```csharp
[Fact]           // Test bez parametrów — jeden scenariusz
[Theory]         // Test z parametrami — wiele scenariuszy
[InlineData()]   // Dane inline dla [Theory]
```

### Przydatne asercje FluentAssertions

```csharp
// Wartości
result.Should().Be(42);
result.Should().NotBeNull();
result.Should().BeGreaterThan(0);

// Stringi
name.Should().Be("Jan");
name.Should().Contain("an");
name.Should().StartWith("J");
name.Should().BeNullOrEmpty();

// Kolekcje
list.Should().HaveCount(3);
list.Should().BeEmpty();
list.Should().Contain(item);
list.Should().AllSatisfy(x => x.IsActive.Should().BeTrue());

// Daty
date.Should().BeCloseTo(DateTime.UtcNow, TimeSpan.FromSeconds(1));
date.Should().BeAfter(startTime);

// Wyjątki (synchroniczne)
var act = () => SomeMethod();
act.Should().Throw<BusinessRuleException>()
   .WithMessage("*already*");

// Wyjątki (asynchroniczne)
var act = () => SomeAsyncMethod();
await act.Should().ThrowAsync<KeyNotFoundException>();

// Guid
id.Should().NotBeEmpty();
id.Should().Be(expectedId);
```

### Kolejność pisania testów

Zacznij od **najłatwiejszych** i buduj pewność siebie:

1. **Encje domenowe** — zero zależności, czysta logika → `AccessCardTests`
2. **Walidatory** — też proste, `TestValidate()` jest intuicyjny
3. **Statyczne utility** — `MqttTopicsTests`
4. **Query handlery** — jeden mock (repozytorium), proste mapowanie
5. **Command handlery** — kilka mocków, bardziej złożone scenariusze

### Szablon nowego testu

Gdy tworzysz nowy plik testowy, użyj tego szablonu:

```csharp
using FluentAssertions;

namespace AccessControl.Domain.Tests.Entities; // ← dopasuj namespace

public class NazwaKlasyTests
{
    [Fact]
    public void MetodaTestowana_Scenariusz_OczekiwanyWynik()
    {
        // Arrange

        // Act

        // Assert
    }
}
```

Dla handlerów z zależnościami:

```csharp
using FluentAssertions;
using NSubstitute;

namespace AccessControl.Application.Tests.NazwaFeaturu;

public class NazwaHandleraTests
{
    private readonly IRepozytorium _repo = Substitute.For<IRepozytorium>();
    private readonly NazwaHandlera _sut;

    public NazwaHandleraTests()
    {
        _sut = new NazwaHandlera(_repo);
    }

    [Fact]
    public async Task Handle_Scenariusz_OczekiwanyWynik()
    {
        // Arrange
        _repo.MetodaAsync(Arg.Any<Guid>(), Arg.Any<CancellationToken>())
            .Returns(wartość);

        // Act
        var result = await _sut.Handle(new Komenda(...), CancellationToken.None);

        // Assert
        result.Should().NotBeEmpty();
    }
}
```

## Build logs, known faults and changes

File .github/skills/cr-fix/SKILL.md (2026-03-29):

---
name: cr-fix
description: "Automatically fix all issues from a Code Review report. Use when: fix CR, napraw CR, popraw CR, wdróż poprawki, fix code review, apply CR fixes, implement review feedback, execute CR recommendations. Reads the CR report from conversation, plans fixes by priority, implements them following Clean Code and senior developer standards, and verifies the build."
argument-hint: "Optional: 'critical' (only 🔴), 'significant' (🔴+🟡), or 'all' (default — 🔴+🟡+🟢)."
---

# CR Fix — Senior Developer Auto-Fixer

You are an experienced Senior Software Engineer. You implement Code Review fixes systematically, writing production-quality code that follows Clean Code, SOLID, DRY, KISS, and defense-in-depth principles.

## Procedure

### 1. Extract findings from the CR report

Scan the conversation history for the most recent Code Review report. It uses this structure:

| Section | Priority | Marker |
|---|---|---|
| Blockers / Critical Issues | 🔴 | Must fix always |
| Architectural Notes / Clean Code | 🟡 | Fix unless arg = `critical` |
| Suggestions & Code | 🟢 | Fix only when arg = `all` or omitted |

Parse each finding into a structured list:
- **Priority** (🔴/🟡/🟢)
- **File & location**
- **Problem description**
- **Suggested fix** (if provided in the CR)

If no CR report is found in conversation — inform the user and stop. Do not invent issues.

### 2. Filter by scope argument

| Argument | Fixes applied |
|---|---|
| `critical` | 🔴 only |
| `significant` | 🔴 + 🟡 |
| `all` or none | 🔴 + 🟡 + 🟢 |

### 3. Plan the fix order

Create a todo list with all fixes. Apply them in this order:

1. **🔴 Critical** — security, race conditions, resource leaks, layer violations
2. **🟡 Significant** — architectural improvements, DRY, validation, performance
3. **🟢 Suggestions** — naming, readability, minor refactors

Within the same priority, order by dependency: if fix B depends on a type/method introduced by fix A, do A first.

### 4. Read before writing

For every file you're about to modify:
- Read the **full current state** of the file (not just the diff).
- Understand the surrounding context, imports, and dependencies.
- If a fix requires a new type/interface, create it before modifying consumers.

### 5. Implement fixes — Quality Standards

Apply each fix following these senior-developer principles:

#### Security (🔴)
- Never expose internal exception messages to API clients. Use dedicated exception types and map them to safe HTTP responses.
- Use TLS/encryption where credentials or commands traverse a network. Add configuration toggles rather than hardcoding.
- Validate all inputs at system boundaries (API, MQTT, file I/O). Fail fast with clear domain errors.
- Never store secrets in source code or version-controlled files. Use environment variables, user-secrets, or vaults.

#### Resource Safety (🔴)
- Dispose patterns: cancel before disconnect, disconnect before dispose. Respect async cancellation.
- Prevent unbounded growth: every in-memory cache must have a TTL or max-size eviction strategy.
- Rate-limit expensive operations (DB writes, network calls) when triggered by high-frequency events.

#### Architecture (🟡)
- Preserve layer separation: Domain → Application → Infrastructure. Never add infrastructure dependencies to Domain.
- Use domain-specific exception types instead of generic framework exceptions (`ArgumentException`, `InvalidOperationException`).
- Extract shared logic into well-named static methods or services. One canonical source of truth per concept.
- When adding a new domain type, also register it in exception handlers, DI containers, and EF configurations as needed.

#### DRY & Consistency (🟡)
- If the same logic appears in ≥2 places, extract it. Place the method where the data lives (entity > service > utility).
- When multiple classes follow the same pattern (e.g., MQTT handlers using regex + extract ID), ensure all follow the same pattern — don't leave outliers.
- Normalize data in one canonical place. Callers should use the shared method.

#### Performance (🟡)
- Use immutable collections (`FrozenDictionary`, `FrozenSet`) for static lookup tables.
- Add in-memory throttling for high-frequency writes (heartbeats, telemetry). Use `ConcurrentDictionary` with timestamp comparison.
- Prefer `AsNoTracking()` for read-only queries. Use tracked queries only when mutations are needed.

#### Readability (🟢)
- Follow project naming conventions. Check how existing code names things before inventing new patterns.
- Keep methods focused. If a method does validation + persistence + notification, consider splitting.
- Guard clauses at the top of methods. Early returns over nested ifs.

### 6. Multi-file edits

When a single logical fix spans multiple files (e.g., new exception type + handler mapping + entity usage):
- Create new files first (types, interfaces).
- Then modify existing files (consumers, DI registration, exception mappers).
- Use `multi_replace_string_in_file` for independent edits in different files to reduce round-trips.

### 7. Infrastructure / Config fixes

For Docker, config, and deployment-related fixes:
- Prefer auto-generation of secrets at container startup over committing secret files.
- Use entrypoint scripts to bootstrap config from environment variables.
- When `.gitignore` excludes a file that's required at runtime, ensure the deployment pipeline creates it.
- For security configs (auth, TLS): default to secure, allow relaxation via explicit opt-in flags.

### 8. Verify

After all fixes are applied:

1. **Build check**: Run `dotnet build --no-restore` (or equivalent for the project).
2. **Error check**: Use `get_errors` on all modified files.
3. If build fails: read the errors, diagnose, fix, and rebuild. Do not leave broken code.
4. If build passes: mark all todos as completed.

### 9. Report

After verification, produce a concise summary:

```
## Wdrożone poprawki z CR

### 🔴 Krytyczne
- [numbered list of what was fixed and where]

### 🟡 Znaczące
- [numbered list]

### 🟢 Sugestie
- [numbered list]
```

For each item: one sentence describing the fix and the file(s) touched. No code blocks unless the fix is non-obvious.

## Response language

**Polish** — unless the user explicitly communicates in English.

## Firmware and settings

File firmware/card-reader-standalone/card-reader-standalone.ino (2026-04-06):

/*
 * AccessControl — Card Reader (standalone)
 * Poprawiona inicjalizacja NFC (bez skanera I2C)
 */

#include <Wire.h>
#include <Adafruit_PN532.h>
#include <ESP8266WiFi.h>
#include <ESP8266mDNS.h>
#include <PubSubClient.h>
#include <WiFiManager.h>
#include <ArduinoJson.h>
#include <EEPROM.h>

// ═══════════════════════════════════════════════════════════
//  CONFIGURATION
// ═══════════════════════════════════════════════════════════

#define LED_R_PIN    D5
#define LED_G_PIN    D6
#define LED_B_PIN    D7
#define BUZZER_PIN   D8

#define MQTT_BROKER_IP   "192.168.0.3"
#define MQTT_PORT        1883
#define MQTT_USERNAME    "dev_mqtt_user"
#define MQTT_PASSWORD    "dev_mqtt_pass123"
#define MQTT_TOPIC_PREFIX "accesscontrol"

#define DEVICE_MODEL     "D1Mini-CardReader"
#define DEVICE_FEATURES  "1"
#define FIRMWARE_VERSION "1.0.0"

#define EEPROM_SIZE              128
#define EEPROM_DEVID_MAGIC       0xAC
#define EEPROM_DEVID_MAGIC_ADDR  0
#define EEPROM_DEVID_HWID_ADDR   1
#define EEPROM_DEVID_HWID_LEN    36
#define EEPROM_CFG_MAGIC         0xCF
#define EEPROM_CFG_MAGIC_ADDR    64
#define EEPROM_CFG_DATA_ADDR     65

#define DEFAULT_HEARTBEAT_INTERVAL  30000
#define DEFAULT_ENROLLMENT_TIMEOUT  30000
#define DEFAULT_BUZZER_ENABLED      true
#define DEFAULT_LED_BRIGHTNESS      128
#define CARD_READ_COOLDOWN          1500

// ═══════════════════════════════════════════════════════════
//  NFC 
// ═══════════════════════════════════════════════════════════
Adafruit_PN532 nfc(2, 3);

// ═══════════════════════════════════════════════════════════
//  GLOBALS
// ═══════════════════════════════════════════════════════════
WiFiClient espClient;
PubSubClient mqtt(espClient);

char hwid[37] = {0};
bool nfcAvailable = false;

struct DeviceConfig {
  uint32_t heartbeatInterval;
  uint32_t enrollmentTimeout;
  bool     buzzerEnabled;
  uint8_t  ledBrightness;
};
DeviceConfig cfg;

enum DeviceMode { MODE_NORMAL, MODE_ENROLLMENT };
DeviceMode currentMode = MODE_NORMAL;
unsigned long enrollmentStartTime = 0;
unsigned long enrollmentTimeoutMs = 0;
unsigned long lastHeartbeat = 0;
unsigned long lastCardRead = 0;
unsigned long lastMqttReconnect = 0;
unsigned long mqttReconnectDelay = 2000;

uint8_t lastUid[7] = {0};
uint8_t lastUidLen = 0;

char topicBuf[128];
char payloadBuf[256];

// ═══════════════════════════════════════════════════════════
//  HELPERS
// ═══════════════════════════════════════════════════════════
void uidToHex(const uint8_t* uid, uint8_t len, char* out) {
  for (uint8_t i = 0; i < len; i++) {
    sprintf(out + (i * 2), "%02X", uid[i]);
  }
  out[len * 2] = '\0';
}

void setStatusLed(uint8_t r, uint8_t g, uint8_t b) {
  float scale = cfg.ledBrightness / 255.0f;
  analogWrite(LED_R_PIN, (int)(r * scale));
  analogWrite(LED_G_PIN, (int)(g * scale));
  analogWrite(LED_B_PIN, (int)(b * scale));
}

void beepOk() {
  digitalWrite(BUZZER_PIN, HIGH);
  delay(80);
  digitalWrite(BUZZER_PIN, LOW);
}

void beepError() {
  for (int i = 0; i < 3; i++) {
    digitalWrite(BUZZER_PIN, HIGH);
    delay(60);
    digitalWrite(BUZZER_PIN, LOW);
    delay(60);
  }
}

// ═══════════════════════════════════════════════════════════
//  EEPROM
// ═══════════════════════════════════════════════════════════
void eepromPutU32(int addr, uint32_t val) {
  EEPROM.write(addr,     (val)       & 0xFF);
  EEPROM.write(addr + 1, (val >> 8)  & 0xFF);
  EEPROM.write(addr + 2, (val >> 16) & 0xFF);
  EEPROM.write(addr + 3, (val >> 24) & 0xFF);
}

uint32_t eepromGetU32(int addr) {
  return (uint32_t)EEPROM.read(addr)
       | ((uint32_t)EEPROM.read(addr + 1) << 8)
       | ((uint32_t)EEPROM.read(addr + 2) << 16)
       | ((uint32_t)EEPROM.read(addr + 3) << 24);
}

void deviceIdInit() {
  EEPROM.begin(EEPROM_SIZE);

  if (EEPROM.read(EEPROM_DEVID_MAGIC_ADDR) == EEPROM_DEVID_MAGIC) {
    for (int i = 0; i < EEPROM_DEVID_HWID_LEN; i++) {
      hwid[i] = (char)EEPROM.read(EEPROM_DEVID_HWID_ADDR + i);
    }
    hwid[EEPROM_DEVID_HWID_LEN] = '\0';
    EEPROM.end();
    return;
  }

  uint8_t mac[6];
  WiFi.macAddress(mac);
  uint8_t bytes[16] = {
    0xAC, 0xCE, 0x55, 0x10,
    0x00, 0x00,
    mac[0], mac[1], mac[2], mac[3], mac[4], mac[5],
    0x00, 0x00, 0x00, 0x00
  };
  bytes[6] = (bytes[6] & 0x0F) | 0x50;
  bytes[8] = (bytes[8] & 0x3F) | 0x80;

  snprintf(hwid, 37,
    "%02x%02x%02x%02x-%02x%02x-%02x%02x-%02x%02x-%02x%02x%02x%02x%02x%02x",
    bytes[0], bytes[1], bytes[2], bytes[3],
    bytes[4], bytes[5], bytes[6], bytes[7],
    bytes[8], bytes[9], bytes[10], bytes[11],
    bytes[12], bytes[13], bytes[14], bytes[15]);

  EEPROM.write(EEPROM_DEVID_MAGIC_ADDR, EEPROM_DEVID_MAGIC);
  for (int i = 0; i < EEPROM_DEVID_HWID_LEN; i++) {
    EEPROM.write(EEPROM_DEVID_HWID_ADDR + i, (uint8_t)hwid[i]);
  }
  EEPROM.commit();
  EEPROM.end();
  Serial.printf("[DeviceId] Generated: %s\n", hwid);
}

void configLoad() {
  EEPROM.begin(EEPROM_SIZE);
  if (EEPROM.read(EEPROM_CFG_MAGIC_ADDR) == EEPROM_CFG_MAGIC) {
    int a = EEPROM_CFG_DATA_ADDR;
    cfg.heartbeatInterval = eepromGetU32(a); a += 4;
    cfg.enrollmentTimeout = eepromGetU32(a); a += 4;
    a += 4; // reserved
    cfg.buzzerEnabled     = EEPROM.read(a++) != 0;
    cfg.ledBrightness     = EEPROM.read(a++);
  } else {
    cfg.heartbeatInterval = DEFAULT_HEARTBEAT_INTERVAL;
    cfg.enrollmentTimeout = DEFAULT_ENROLLMENT_TIMEOUT;
    cfg.buzzerEnabled     = DEFAULT_BUZZER_ENABLED;
    cfg.ledBrightness     = DEFAULT_LED_BRIGHTNESS;
  }
  EEPROM.end();
}

void configSave() {
  EEPROM.begin(EEPROM_SIZE);
  EEPROM.write(EEPROM_CFG_MAGIC_ADDR, EEPROM_CFG_MAGIC);
  int a = EEPROM_CFG_DATA_ADDR;
  eepromPutU32(a, cfg.heartbeatInterval); a += 4;
  eepromPutU32(a, cfg.enrollmentTimeout); a += 4;
  a += 4; // reserved
  EEPROM.write(a++, cfg.buzzerEnabled ? 1 : 0);
  EEPROM.write(a++, cfg.ledBrightness);
  EEPROM.commit();
  EEPROM.end();
}

// ═══════════════════════════════════════════════════════════
//  MQTT
// ═══════════════════════════════════════════════════════════
void mqttPublishCard(const char* action, const uint8_t* uid, uint8_t uidLen) {
  if (!mqtt.connected()) return;
  char uidHex[15];
  uidToHex(uid, uidLen, uidHex);
  snprintf(topicBuf, sizeof(topicBuf), "%s/%s/card/%s", MQTT_TOPIC_PREFIX, hwid, action);
  snprintf(payloadBuf, sizeof(payloadBuf), "{\"uid\":\"%s\",\"uidLen\":%d}", uidHex, uidLen);
  mqtt.publish(topicBuf, payloadBuf);
  Serial.printf("[Card] %s: %s\n", action, uidHex);
}

void sendHeartbeat() {
  if (!mqtt.connected()) return;
  snprintf(topicBuf, sizeof(topicBuf), "%s/%s/heartbeat", MQTT_TOPIC_PREFIX, hwid);
  snprintf(payloadBuf, sizeof(payloadBuf),
    "{\"status\":\"online\",\"uptime\":%lu,\"rssi\":%d,\"freeHeap\":%u,\"nfc\":%s}",
    millis() / 1000, WiFi.RSSI(), ESP.getFreeHeap(),
    nfcAvailable ? "true" : "false");
  mqtt.publish(topicBuf, payloadBuf, true);
}

void mqttCallback(char* topic, byte* payload, unsigned int length) {
  Serial.printf("[MQTT] %s (%u bytes)\n", topic, length);

  char json[256];
  unsigned int copyLen = (length < sizeof(json) - 1) ? length : sizeof(json) - 1;
  memcpy(json, payload, copyLen);
  json[copyLen] = '\0';

  // Config update
  char configTopic[128];
  snprintf(configTopic, sizeof(configTopic), "%s/%s/config/set", MQTT_TOPIC_PREFIX, hwid);
  if (strcmp(topic, configTopic) == 0) {
    JsonDocument doc;
    if (deserializeJson(doc, json)) return;

    bool changed = false;
    if (doc["heartbeatInterval"].is<uint32_t>()) { cfg.heartbeatInterval = doc["heartbeatInterval"]; changed = true; }
    if (doc["enrollmentTimeout"].is<uint32_t>()) { cfg.enrollmentTimeout = doc["enrollmentTimeout"]; changed = true; }
    if (doc["buzzerEnabled"].is<bool>())         { cfg.buzzerEnabled = doc["buzzerEnabled"];         changed = true; }
    if (doc["ledBrightness"].is<uint8_t>())      { cfg.ledBrightness = doc["ledBrightness"];         changed = true; }

    if (changed) configSave();

    char ackTopic[128];
    snprintf(ackTopic, sizeof(ackTopic), "%s/%s/config/ack", MQTT_TOPIC_PREFIX, hwid);
    mqtt.publish(ackTopic, "{\"applied\":true}");
    Serial.println("[Config] Updated");
    return;
  }

  // Enrollment
  char enrollTopic[128];
  snprintf(enrollTopic, sizeof(enrollTopic), "%s/%s/card/enroll", MQTT_TOPIC_PREFIX, hwid);
  if (strcmp(topic, enrollTopic) == 0) {
    JsonDocument doc;
    if (deserializeJson(doc, json)) return;

    const char* action = doc["action"] | "start";
    if (strcmp(action, "cancel") == 0) {
      if (currentMode == MODE_ENROLLMENT) {
        currentMode = MODE_NORMAL;
        setStatusLed(0, 255, 0);
        Serial.println("[Enroll] Cancelled");
      }
      return;
    }

    uint32_t timeoutSec = doc["timeout"] | (cfg.enrollmentTimeout / 1000);
    enrollmentTimeoutMs = timeoutSec * 1000UL;
    enrollmentStartTime = millis();
    currentMode = MODE_ENROLLMENT;
    setStatusLed(255, 165, 0);
    Serial.printf("[Enroll] Active (timeout %us)\n", timeoutSec);
    return;
  }
}

void mqttConnect() {
  char lwtTopic[128];
  snprintf(lwtTopic, sizeof(lwtTopic), "%s/%s/heartbeat", MQTT_TOPIC_PREFIX, hwid);
  bool ok = mqtt.connect(hwid, MQTT_USERNAME, MQTT_PASSWORD, lwtTopic, 1, true, "{\"status\":\"offline\"}");
  if (ok) {
    Serial.println("[MQTT] Connected!");
    mqttReconnectDelay = 2000;
    snprintf(topicBuf, sizeof(topicBuf), "%s/%s/config/set", MQTT_TOPIC_PREFIX, hwid);
    mqtt.subscribe(topicBuf, 1);
    snprintf(topicBuf, sizeof(topicBuf), "%s/%s/card/enroll", MQTT_TOPIC_PREFIX, hwid);
    mqtt.subscribe(topicBuf, 1);
  } else {
    Serial.printf("[MQTT] Failed rc=%d\n", mqtt.state());
  }
}

void mqttReconnectLoop() {
  if (mqtt.connected()) { mqtt.loop(); return; }
  unsigned long now = millis();
  if (now - lastMqttReconnect < mqttReconnectDelay) return;
  lastMqttReconnect = now;
  Serial.printf("[MQTT] Reconnecting (delay %lums)...\n", mqttReconnectDelay);
  mqttConnect();
  if (!mqtt.connected()) {
    mqttReconnectDelay = min(mqttReconnectDelay * 2, (unsigned long)30000);
  }
}

// ═══════════════════════════════════════════════════════════
//  mDNS
// ═══════════════════════════════════════════════════════════
void mdnsInit() {
  char hostname[32];
  snprintf(hostname, sizeof(hostname), "ac-%.8s", hwid);
  WiFi.hostname(hostname);

  if (!MDNS.begin(hostname)) {
    Serial.println("[mDNS] Failed!");
    return;
  }

  MDNS.addService("_accesscontrol", "_tcp", 80);
  MDNS.addServiceTxt("_accesscontrol", "_tcp", "hwid", hwid);
  MDNS.addServiceTxt("_accesscontrol", "_tcp", "model", DEVICE_MODEL);

  uint8_t mac[6];
  WiFi.macAddress(mac);
  char macStr[18];
  snprintf(macStr, sizeof(macStr), "%02X:%02X:%02X:%02X:%02X:%02X",
           mac[0], mac[1], mac[2], mac[3], mac[4], mac[5]);
  MDNS.addServiceTxt("_accesscontrol", "_tcp", "mac", macStr);
  MDNS.addServiceTxt("_accesscontrol", "_tcp", "features", DEVICE_FEATURES);
  MDNS.addServiceTxt("_accesscontrol", "_tcp", "fw", FIRMWARE_VERSION);

  Serial.printf("[mDNS] %s advertising\n", hostname);
}

// ═══════════════════════════════════════════════════════════
//  I2C BUS RECOVERY
// ═══════════════════════════════════════════════════════════
void i2cBusRecovery() {
  Serial.println("[I2C] Bus recovery...");
  pinMode(D1, OUTPUT);     // SCL
  pinMode(D2, INPUT_PULLUP); // SDA
  for (int i = 0; i < 18; i++) {
    digitalWrite(D1, LOW);
    delayMicroseconds(5);
    digitalWrite(D1, HIGH);
    delayMicroseconds(5);
  }
  // STOP condition
  pinMode(D2, OUTPUT);
  digitalWrite(D2, LOW);
  delayMicroseconds(5);
  digitalWrite(D1, HIGH);
  delayMicroseconds(5);
  digitalWrite(D2, HIGH);
  delayMicroseconds(5);
}

// ═══════════════════════════════════════════════════════════
//  SETUP
// ═══════════════════════════════════════════════════════════
void setup() {
  Serial.begin(115200);
  delay(500);
  Serial.println("\n\n========================================");
  Serial.println("  AccessControl Card Reader (standalone)");
  Serial.println("========================================");

  // ---- NFC ABSOLUTELY FIRST — identical to working test sketch ----
  // Do NOT call Wire.begin(), bus recovery, WiFi.mode, or ANYTHING before this.
  // nfc.begin() internally calls Wire.begin() with correct default pins.
  nfc.begin();
  uint32_t versiondata = nfc.getFirmwareVersion();

  if (!versiondata) {
    // First attempt failed — wait and retry (no bus recovery — it makes things worse)
    Serial.println("[NFC] Attempt 1 failed, retrying...");
    delay(500);
    nfc.begin();
    delay(100);
    versiondata = nfc.getFirmwareVersion();
  }

  if (!versiondata) {
    Serial.println("[NFC] PN532 NOT FOUND! Sprawdz kable.");
    nfcAvailable = false;
  } else {
    nfcAvailable = true;
    Serial.printf("[NFC] PN5%02X fw %d.%d — OK!\n",
      (versiondata >> 24) & 0xFF,
      (versiondata >> 16) & 0xFF,
      (versiondata >> 8) & 0xFF);
    nfc.SAMConfig();
    nfc.setPassiveActivationRetries(0x01);
  }

  // ---- LED & Buzzer (after NFC) ----
  pinMode(LED_R_PIN, OUTPUT);
  pinMode(LED_G_PIN, OUTPUT);
  pinMode(LED_B_PIN, OUTPUT);
  pinMode(BUZZER_PIN, OUTPUT);
  digitalWrite(BUZZER_PIN, LOW);

  configLoad();
  setStatusLed(0, 0, 255);

  // ---- Device ID ----
  deviceIdInit();
  Serial.printf("HWID: %s\n", hwid);

  // ---- WiFi ----
  setStatusLed(0, 0, 128);
  {
    WiFiManager wm;
    wm.setConnectTimeout(30);
    wm.setConfigPortalTimeout(180);
    uint8_t mac[6];
    WiFi.macAddress(mac);
    char apName[24];
    snprintf(apName, sizeof(apName), "AccessControl-%02X%02X", mac[4], mac[5]);
    Serial.printf("[WiFi] AP: %s\n", apName);
    if (!wm.autoConnect(apName)) {
      Serial.println("[WiFi] Failed — restarting");
      ESP.restart();
    }
  }
  Serial.printf("[WiFi] IP: %s\n", WiFi.localIP().toString().c_str());

  // ---- Reinit I2C after WiFi (WiFi can mess with pin muxing) ----
  Wire.begin(D2, D1);
  Wire.setClock(100000);
  Wire.setClockStretchLimit(230000);

  // ---- mDNS ----
  mdnsInit();

  // ---- MQTT ----
  mqtt.setBufferSize(512);
  mqtt.setCallback(mqttCallback);
  Serial.printf("[MQTT] Broker: %s:%d\n", MQTT_BROKER_IP, MQTT_PORT);
  mqtt.setServer(MQTT_BROKER_IP, MQTT_PORT);
  mqttConnect();

  // ---- Ready ----
  if (nfcAvailable) setStatusLed(0, 255, 0);
  else              setStatusLed(255, 165, 0);
  beepOk();
  sendHeartbeat();
  Serial.println("[Ready] Waiting for cards...");
}

// ═══════════════════════════════════════════════════════════
//  LOOP
// ═══════════════════════════════════════════════════════════
void loop() {
  mqttReconnectLoop();
  MDNS.update();

  unsigned long now = millis();

  if (now - lastHeartbeat >= cfg.heartbeatInterval) {
    sendHeartbeat();
    lastHeartbeat = now;
  }

  if (currentMode == MODE_ENROLLMENT && (now - enrollmentStartTime >= enrollmentTimeoutMs)) {
    Serial.println("[Enroll] Timeout");
    currentMode = MODE_NORMAL;
    setStatusLed(0, 255, 0);
  }

  if (!nfcAvailable) {
    delay(100);
    return;
  }

  uint8_t uid[7] = {0};
  uint8_t uidLen = 0;

  if (nfc.readPassiveTargetID(PN532_MIFARE_ISO14443A, uid, &uidLen, 100)) {
    bool sameCard = (uidLen == lastUidLen) && (memcmp(uid, lastUid, uidLen) == 0);
    if (!sameCard || (now - lastCardRead > CARD_READ_COOLDOWN)) {
      memcpy(lastUid, uid, uidLen);
      lastUidLen = uidLen;
      lastCardRead = now;

      if (currentMode == MODE_ENROLLMENT) {
        setStatusLed(0, 255, 255);
        if (cfg.buzzerEnabled) { beepOk(); delay(50); beepOk(); }
        mqttPublishCard("enrolled", uid, uidLen);
        currentMode = MODE_NORMAL;
        delay(200);
        setStatusLed(0, 255, 0);
      } else {
        setStatusLed(0, 0, 255);
        if (cfg.buzzerEnabled) beepOk();
        mqttPublishCard("scanned", uid, uidLen);
        delay(200);
        setStatusLed(0, 255, 0);
      }
    }
  }
}

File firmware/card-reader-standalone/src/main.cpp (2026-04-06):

/*
 * AccessControl — Card Reader + Lock Controller (all-in-one)
 *
 * Hardware: Arduino Nano ESP32 (ESP32-S3) + PN532 NFC/RFID (I2C)
 *           + HW-482 Relay Module + RGB LED (CC) + TMB12A05 Buzzer
 *
 * Pin connections:
 *   PN532 SDA  → A4 (GPIO11) — default I2C SDA
 *   PN532 SCL  → A5 (GPIO12) — default I2C SCL
 *   PN532 VCC  → 3V3
 *   PN532 GND  → GND
 *   PN532 DIP: SW1=ON, SW2=OFF (I2C mode)
 *
 *   LED_R      → D2 (GPIO5)
 *   LED_G      → D3 (GPIO6)
 *   LED_B      → D4 (GPIO7)
 *   BUZZER     → D5 (GPIO8)  — TMB12A05 active buzzer, 5V
 *   HW-482 IN1 → D6 (GPIO9)  — relay, active LOW
 *   HW-482 VCC → 5V (VUSB)
 *   HW-482 GND → GND
 *   RESET BTN  → D7 (GPIO10) ↔ GND (INPUT_PULLUP, hold 3s at boot)
 */

#include <Arduino.h>
#include <Wire.h>
#include <Adafruit_PN532.h>
#include <WiFi.h>
#include <ESPmDNS.h>
#include <PubSubClient.h>
#include <WiFiManager.h>
#include <ArduinoJson.h>
#include <WebServer.h>
#include <EEPROM.h>

// ═══════════════════════════════════════════════════════════
//  CONFIGURATION
// ═══════════════════════════════════════════════════════════

#define LED_R_PIN      D2   // GPIO5
#define LED_G_PIN      D3   // GPIO6
#define LED_B_PIN      D4   // GPIO7
#define BUZZER_PIN     D5   // GPIO8
#define RELAY_PIN      D6   // GPIO9  — HW-482 relay, active LOW
#define RESET_BTN_PIN  D7   // GPIO10 — factory reset button, active LOW

#define MQTT_TOPIC_PREFIX "accesscontrol"

#define DEVICE_MODEL     "NanoESP32-CardReader"
#define DEVICE_FEATURES  "17"
#define FIRMWARE_VERSION "2.0.0"

#define EEPROM_SIZE              256
#define EEPROM_DEVID_MAGIC       0xAC
#define EEPROM_DEVID_MAGIC_ADDR  0
#define EEPROM_DEVID_HWID_ADDR   1
#define EEPROM_DEVID_HWID_LEN    36
#define EEPROM_CFG_MAGIC         0xD0
#define EEPROM_CFG_MAGIC_ADDR    64
#define EEPROM_CFG_DATA_ADDR     65

// MQTT provisioning EEPROM layout (addr 96-227)
#define EEPROM_MQTT_MAGIC        0x4D
#define EEPROM_MQTT_MAGIC_ADDR   96
#define EEPROM_MQTT_DATA_ADDR    97
#define EEPROM_MQTT_BROKER_LEN   64
#define EEPROM_MQTT_USER_LEN     32
#define EEPROM_MQTT_PASS_LEN     32

#define DEFAULT_HEARTBEAT_INTERVAL  30000
#define DEFAULT_ENROLLMENT_TIMEOUT  30000
#define DEFAULT_BUZZER_ENABLED      true
#define DEFAULT_LED_BRIGHTNESS      128
#define DEFAULT_LOCK_DURATION       5000
#define CARD_READ_COOLDOWN          1500
#define FACTORY_RESET_HOLD_MS       3000
#define RESULT_TIMEOUT_MS           5000

// ═══════════════════════════════════════════════════════════
//  NFC
// ═══════════════════════════════════════════════════════════
// I2C polling mode: pass -1 for IRQ so library polls I2C ready byte
// instead of waiting on an unconnected IRQ pin
Adafruit_PN532 nfc(-1, -1, &Wire);

// ═══════════════════════════════════════════════════════════
//  GLOBALS
// ═══════════════════════════════════════════════════════════
WiFiClient espClient;
PubSubClient mqtt(espClient);

static char hwid[37] = {0};
static bool nfcAvailable = false;

struct MqttConfig {
    char     broker[64];
    uint16_t port;
    char     username[32];
    char     password[32];
};
static MqttConfig mqttCfg;

struct DeviceConfig {
    uint32_t heartbeatInterval;
    uint32_t enrollmentTimeout;
    bool     buzzerEnabled;
    uint8_t  ledBrightness;
    uint32_t lockOpenDuration;
};
static DeviceConfig cfg;

enum DeviceMode { MODE_NORMAL, MODE_ENROLLMENT };
static DeviceMode currentMode = MODE_NORMAL;
static unsigned long enrollmentStartTime = 0;
static unsigned long enrollmentTimeoutMs = 0;
static unsigned long lastHeartbeat = 0;
static unsigned long lastCardRead = 0;
static unsigned long lastMqttReconnect = 0;
static unsigned long mqttReconnectDelay = 2000;

// Relay / lock state
static unsigned long lockCloseTime = 0;

// LED feedback timer (non-blocking restore to default color)
static unsigned long ledFeedbackEndTime = 0;

// Enrollment blink state
static unsigned long enrollBlinkTimer = 0;
static bool enrollBlinkState = false;

// Card result waiting
static bool waitingForResult = false;
static unsigned long resultTimeoutTime = 0;

static bool mqttProvisioned = false;
static WebServer provisionServer(80);
static bool provisionServerActive = false;

static uint8_t lastUid[7] = {0};
static uint8_t lastUidLen = 0;

static char topicBuf[128];
static char payloadBuf[256];

// ═══════════════════════════════════════════════════════════
//  HELPERS
// ═══════════════════════════════════════════════════════════
void uidToHex(const uint8_t* uid, uint8_t len, char* out) {
    for (uint8_t i = 0; i < len; i++) {
        sprintf(out + (i * 2), "%02X", uid[i]);
    }
    out[len * 2] = '\0';
}

void setStatusLed(uint8_t r, uint8_t g, uint8_t b) {
    // Use digitalWrite only — analogWrite/PWM creates timer interrupts
    // that corrupt software I2C timing on ESP8266
    digitalWrite(LED_R_PIN, r > 127 ? HIGH : LOW);
    digitalWrite(LED_G_PIN, g > 127 ? HIGH : LOW);
    digitalWrite(LED_B_PIN, b > 127 ? HIGH : LOW);
}

void beepOk() {
    digitalWrite(BUZZER_PIN, HIGH);
    delay(80);
    digitalWrite(BUZZER_PIN, LOW);
}

void beepError() {
    for (int i = 0; i < 3; i++) {
        digitalWrite(BUZZER_PIN, HIGH);
        delay(60);
        digitalWrite(BUZZER_PIN, LOW);
        delay(60);
    }
}

void beepDouble() {
    digitalWrite(BUZZER_PIN, HIGH);
    delay(80);
    digitalWrite(BUZZER_PIN, LOW);
    delay(60);
    digitalWrite(BUZZER_PIN, HIGH);
    delay(80);
    digitalWrite(BUZZER_PIN, LOW);
}

void setDefaultLed() {
    if (currentMode == MODE_ENROLLMENT) return;
    if (nfcAvailable) setStatusLed(0, 0, 255);   // blue = ready
    else              setStatusLed(255, 165, 0);  // orange = NFC unavailable
}

// ═══════════════════════════════════════════════════════════
//  EEPROM
// ═══════════════════════════════════════════════════════════
void eepromPutU32(int addr, uint32_t val) {
    EEPROM.write(addr,     (val)       & 0xFF);
    EEPROM.write(addr + 1, (val >> 8)  & 0xFF);
    EEPROM.write(addr + 2, (val >> 16) & 0xFF);
    EEPROM.write(addr + 3, (val >> 24) & 0xFF);
}

uint32_t eepromGetU32(int addr) {
    return (uint32_t)EEPROM.read(addr)
         | ((uint32_t)EEPROM.read(addr + 1) << 8)
         | ((uint32_t)EEPROM.read(addr + 2) << 16)
         | ((uint32_t)EEPROM.read(addr + 3) << 24);
}
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

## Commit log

2026-03-27 feat(api): wire up auth endpoint, middleware and configuration
    - Add login endpoint (POST /api/auth/login) with MediatR
    - Configure authentication and authorization middleware pipeline
    - Add auto-migration and admin seeding on startup
    - Add Scalar API reference for development
    - Add health check endpoint
    - Update appsettings with JWT and EF logging configuration
2026-03-27 chore: add Docker setup with multi-stage build and compose
    - Add multi-stage Dockerfile with non-root user
    - Add docker-compose with PostgreSQL and app services
    - Add .env.example with all required environment variables
    - Add .dockerignore to optimize build context
    - Add README
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2026-03-28 feat(ui): add login page
    - MudBlazor card layout with email and password fields
    - DataAnnotations validation via EditForm + DataAnnotationsValidator
    - Loading spinner on submit button during async call
    - Error alert displayed on failed login attempt
    - try/finally ensures loading state is always reset
    - Navigates to / on successful login
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2026-03-28 feat(infrastructure): add device adapters, resolver, repository and mDNS discovery service
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2026-03-29 Add enrollment commands (start/cancel), config update command; use BusinessRuleException in device registration
2026-03-29 Configure AccessCard entity and JSONB device config in EF Core, add AccessCards DbSet
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2026-03-29 Replace MdnsDeviceDiscoveryService with dual-cache DeviceDiscoveryService (mDNS + MQTT)
2026-03-29 Add MQTT infrastructure: options, background client, heartbeat throttler, broker mDNS advertiser
2026-03-29 Register MQTT, device discovery and card services in DI; add MQTTnet and Makaretu.Dns packages
2026-03-29 Add card REST endpoints, update device endpoints and exception handler, add MQTT config
2026-03-30 feat(ui): switch UI labels to English
    - MainLayout: navigation, menu items, login/logout buttons
    - Login page: title, form labels, button text, validation messages
    - Update copilot-instructions.md to reflect English UI convention
2026-03-30 feat: add dev data seeder and NpgsqlDataSource DI improvements
    Backend:
    - Register NpgsqlDataSource via factory singleton (proper Dispose)
    - Use NpgsqlDataSource with EnableDynamicJson for DbContext
    - Add DevDataSeeder: seeds users, devices, and access cards
    - Wrap EF Core seed operations in a transaction
    - Add POST /api/dev/seed endpoint (Admin-only, dev environment)
    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
2026-03-30 feat(ui): add Dashboard, Devices, Device detail, and Zones pages
    - Replace Home.razor with Dashboard page
    - Add Devices list page with status indicators
    - Add Device detail page (general info, features)
    - Add Access Zones placeholder page
    - Extract shared DeviceItem record and DeviceHelpers to Models/
    - Add navigation links in MainLayout sidebar
    - Register AccessControl.UI.Models in _Imports.razor
2026-03-31 docs(enclosure): add parametric OpenSCAD enclosure for card-reader
    Add OpenSCAD model with top/bottom parts, screw mounts, ventilation,
    status LED slot, and RC522 antenna window. Includes build script
    (build.ps1) for automated STL generation and pre-built output STLs.
    [enclosure.scad, enclosure_bottom.stl, enclosure_top.stl]
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2026-04-04 feat: add zones CRUD, access logs, SignalR notifications; refactor MQTT topics
    - Add AccessZone CRUD (commands, queries, validators, repository, endpoints)
    - Add AccessLog persistence and paged query with filtering
    - Add SignalR hub for real-time access event notifications
    - Refactor MQTT topics: card/read -> card/scanned, config/update -> config/set
    - Rename CardReadMqttHandler to CardScannedMqttHandler
    - Add case-insensitive JSON deserialization for MQTT handlers
    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
2026-04-04 feat: add Blazor UI for zones, cards, access logs, device discovery
    - Add Zones page with create/edit/delete dialogs
    - Add Cards page with search, zone filter, enroll and edit dialogs
    - Add Access Logs page with live SignalR feed and paginated history
    - Add device discovery scan UI with add-device dialog
    - Add UI services: ZoneService, CardService, DeviceService, AccessHubService
    - Add UI models for cards, zones, access logs, enrolled cards, discovered devices
    - Add DeviceHelpers.HasCardReader() to replace magic number
    - Add navigation links for Cards and Access Logs in sidebar
    - Register new services in Program.cs and update _Imports.razor
    - Fix information disclosure: use generic error mes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
2026-04-04 chore: update Dockerfile, .gitignore, copilot-instructions
    - Fix Dockerfile: use groupadd/useradd instead of addgroup/adduser (Debian)
    - Update .gitignore with additional patterns
    - Update copilot-instructions.md with current project conventions
2026-04-04 chore: remove generated STL files from repo
    [enclosure_bottom.stl, enclosure_top.stl]
2026-04-06 infra: add split docker-compose and update dev config
    - Add docker-compose.infra.yml for standalone Mosquitto + PostgreSQL
    - Add docker-compose.override.yml for dev overrides
    - Add MQTT credentials to .env.example with sync note
    - Bind API to 0.0.0.0:5104 so ESP32 devices can reach it on LAN
2026-04-06 feat: reorder card access flow and add card/result topic
    - Persist audit log before MQTT publish (ensures record on publish failure)
    - Send access result back to scanning device via card/result topic
    - Include lockOpenDurationSec from device config in lock commands
    - Send lock commands to all zone devices including self (combo readers)
    - Materialize lock task list before Task.WhenAll to prevent lazy re-evaluation
2026-04-06 feat: add CardReaderWithLock device adapter
    - New combo adapter supporting both CardReader and LockControl features
    - Add CardReaderWithLock to DeviceAdapterType enum
    - Register adapter in DI container
2026-04-06 feat: add device provisioning (push MQTT config over HTTP)
    - Add IDeviceProvisioningService interface and HTTP implementation
    - Add ProvisionDeviceCommand + handler (MediatR CQRS)
    - Add POST /api/devices/{id}/provision endpoint
    - Auto-provision on device creation (non-blocking, retry via endpoint)
    - Add SSRF validation: reject loopback/broadcast IPs
    - Add DeviceProvisionResult DTO (Application + UI)
    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
2026-04-06 fix(ui): change AccessHubService to Scoped lifetime
    - Singleton was incorrect for a service depending on scoped HttpClient
    - Add ESP32 card-reader standalone firmware (PlatformIO)
    [card-reader-standalone.ino, main.cpp]
2026-04-06 docs: update README with security notes and setup guide
    - Document 0.0.0.0 binding security implications
    - Document plaintext provisioning limitation (ESP32 no TLS)
    - Recommend per-device MQTT credentials for production
2026-04-06 feat(api): add fluent CrudEndpointExtensions for minimal API CQRS endpoints
    Introduces reusable RouteGroupBuilder extension methods (WithGetAll, WithGetById,
    WithCreate, WithUpdate, WithDelete) that chain on top of any MapGroup() call.
    Each operation is optional — compose only what you need.
    WithCreate uses CreatedAtRoute() to avoid hardcoded URL prefixes.
2026-04-06 refactor(api): migrate CardEndpoints and ZoneEndpoints to fluent CRUD helpers
    Reduces ~50 lines of boilerplate per resource to a single fluent chain.
    Switches from Results.Created(url) to CreatedAtRoute(endpointName) for
    consistent Location header generation without duplicating route prefixes.
2026-04-06 feat(domain): add Device.Update() and IDeviceRepository.DeleteAsync()
    Device.Update() validates name/zoneId and mutates state with UpdatedAt timestamp.
    Name changed from required init to private set to allow mutation while keeping
    construction exclusively through Device.Create() factory method.
    DeleteAsync added to IDeviceRepository interface and implemented in EF repository.
2026-04-06 feat(application): add UpdateDevice and DeleteDevice CQRS commands
    UpdateDeviceCommand: updates device Name and ZoneId via Device.Update(),
    includes FluentValidation (NotEmpty name, non-empty ZoneId).
    DeleteDeviceCommand: loads tracked entity and removes it from the repository.
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2026-04-07 feat(ui): add Cardholder & AccessProfile pages, refactor Cards UI
    - Add Cardholders page with CRUD dialog
    - Add AccessProfiles page with CRUD dialog
    - Add CardholderService, AccessProfileService with interfaces
    - Refactor Cards page: replace Zone filter with Cardholder search
    - Refactor EditCardDialog: Cardholder select instead of Zone select
    - Update Card detail page: show CardholderName
    - Update Zones page: show ProfileCount instead of CardCount
    - Add navigation links for Cardholders and Access Profiles
    - Register new services in DI
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2026-04-11 test: add AccessCard unit tests and fix NormalizeUid assertion
    - Add tests for NormalizeUid, AssignCardholder, UnassignCardholder,
    Update and Deactivate methods
    - Fix BeEquivalentTo -> Be() in NormalizeUid test (case-sensitive check)
    - Change label from Polish to English in Create test
    - Restore Python gitignore rules (__pycache__, *.pyc)
2026-04-12 test: add Device entity tests
    Cover Create, RecordHeartbeat, Update, and UpdateConfiguration
    with boundary testing for all 5 config keys (lockOpenDurationSec,
    heartbeatIntervalSec, enrollmentTimeoutSec, buzzerEnabled,
    ledBrightness), key canonicalization, and overwrite behavior.
    32 tests total.
